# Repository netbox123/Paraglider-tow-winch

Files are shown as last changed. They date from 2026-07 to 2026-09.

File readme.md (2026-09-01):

# Paraglider Tow Winch

Version 0.2

An open-source electric tow winch for paragliding, designed with safety, reliability and maintainability as the primary goals.

The project combines:

- Parametric mechanical design in FreeCAD
- Python-generated CAD models
- Direct rope tension measurement using a load cell
- PID-controlled electric drive
- Automatic level winding using a self-reversing traverse screw
- Open documentation and engineering calculations

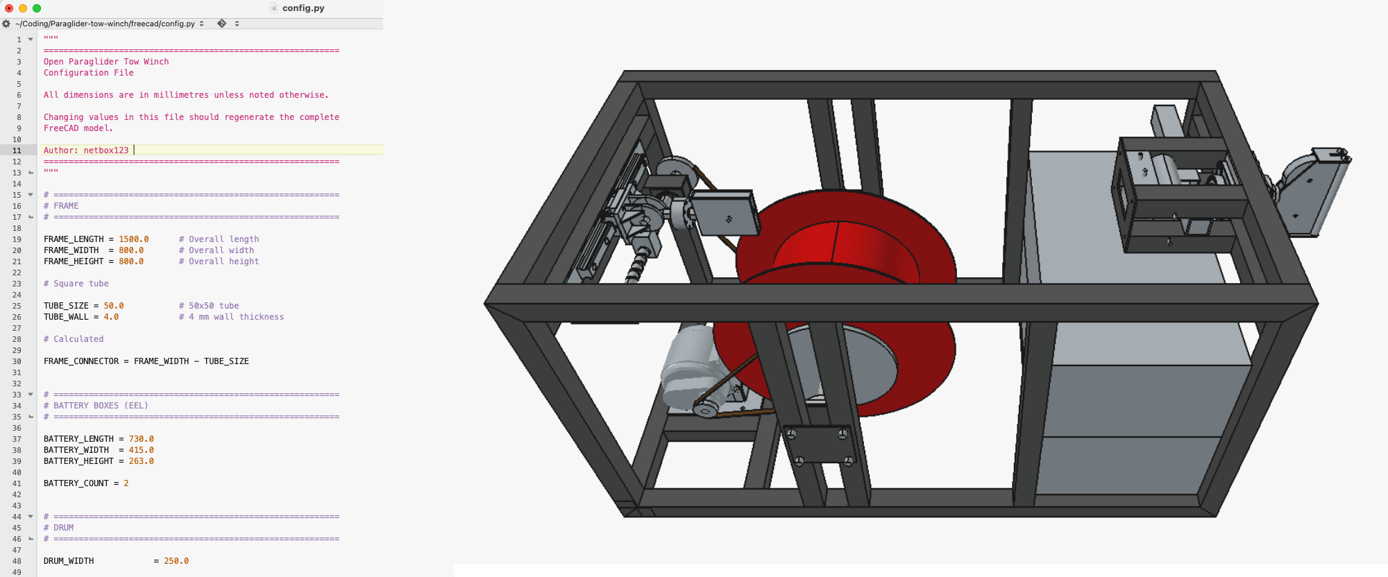
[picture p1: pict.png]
Parametric FreeCAD model of the tow winch frame, drum, drivetrain, level wind and battery boxes


## Project Goals

The aim is to build a tow winch that:

- Maintains constant tow force independent of drum diameter.
- Winds the rope neatly during both retrieval and payout.
- Minimizes side loads on the level wind mechanism.
- Is easy to maintain using commercially available components.
- Can be reproduced and improved by other clubs.

## Current Concept

### Frame

- 1500 × 800 × 800 mm
- 50 × 50 × 4 mm square steel tube

### Drum

- Width: 250 mm
- Core diameter: 390 mm
- Flange diameter: 590 mm
- 5 mm steel shell
- 5 mm steel flanges
- 50 mm shaft
- Internal stiffening discs

### Power

Planned motor:

- QS165 12 kW
- 2.37:1 gearbox

### Rope

- 3 mm Dyneema
- Approximately 1500 m
- Typical tow tension: 40–100 kg

### Level Wind

A mechanically synchronized self-reversing traverse screw ("diamond screw" or "level wind screw") is used instead of a stepper motor.

Advantages:

- Works automatically in both winding directions.
- Always remains synchronized with the drum.
- No electronic positioning required.

### Tension Control

Tow force will be measured directly with a load cell mounted beneath the moving guide pulley.

Benefits:

- Direct measurement of rope tension.
- Independent of drum diameter.
- Independent of gearbox efficiency.
- Independent of motor current.
- Improved PID control.

## Software

The FreeCAD model is generated from Python macros (`freecad/`), one module per subsystem, all driven from a single [`config.py`](freecad/config.py).

The intention is that the complete winch can be regenerated from a small set of configuration parameters.

Modules built so far:

- Frame (hollow mitred tube)
- Battery boxes
- Drum (barrel, flanges, shaft, bearings)
- Motor mount and chain drivetrain (motor, sprockets)
- Rope intake (self-aligning swivel, rollers, guide wheels, line cutter)
- Level wind (Hiwin linear rail, self-reversing screw, flange bearings)
- Winding pulley and load cell mount (rod-end pivot)
- Operator-display panel-mount frame ([`gigadisplay_holder/`](gigadisplay_holder/) - a separate small parametric part, 3D-printed, fitted to the real GIGA Display Shield)

Still open:

- Electronics firmware - mainboard PCB (ESP32-S3) is designed, placed, routed and ready to order (see [docs/electronics.md](docs/electronics.md)); firmware itself has only a first communications skeleton so far, no control logic yet (see [docs/software.md](docs/software.md))
- CAN vs. analog throttle control - Fardriver's CAN61 protocol spec is in hand but not yet confirmed on real hardware; analog throttle kept as the wired fallback either way
- Frame cross-member mitres
- Motor mount bracket (currently a placeholder)

### Running the model

1. Install [FreeCAD](https://www.freecad.org/) (1.1 or newer).
2. Open FreeCAD and use **Macro → Macros… → Execute** to run [`freecad/main.py`](freecad/main.py), or open it in the built-in Python console and run it directly.
3. [`main.py`](freecad/main.py) creates a new `TowWinch` document and builds the complete model from [`config.py`](freecad/config.py). Edit values in [`config.py`](freecad/config.py) and re-run the macro to regenerate the model.

The model can also be regenerated headless (no GUI) with `freecadcmd freecad/main.py`, useful for scripted checks.

The operator-display frame in [`gigadisplay_holder/`](gigadisplay_holder/) is a self-contained parametric part with its own `config.py`; build it with `freecadcmd gigadisplay_holder/build.py`. See its [README](gigadisplay_holder/README.md).

## Status

The FreeCAD model is parametric and covers the mechanical structure end-to-end: frame, drum, drivetrain, rope intake and level wind. The electronics mainboard (ESP32-S3) is fully designed - schematic and PCB placed/routed, ready to order (see [docs/electronics.md](docs/electronics.md)). Firmware work has started: the GIGA/pilot-handheld JSON protocol is defined and a first communications-only skeleton exists (see [docs/software.md](docs/software.md), [`firmware/esp32_mainboard/`](firmware/esp32_mainboard/)) - the real control system (PID, CAN61, sensors) is not built yet.

Fabrication of the frame has already started in parallel with the CAD work (see [docs/build_log.md](docs/build_log.md)).

See [docs/todo.md](docs/todo.md) for the detailed, up-to-date task list.

## Documentation

- [Mission statement](docs/mission_statement.md)
- [History and design philosophy](docs/history.md)
- [Control philosophy](docs/control_philosophy.md)
- [Electronics architecture](docs/electronics.md)
- [Software architecture](docs/software.md)
- [Design decisions](docs/design_decisions.md)
- [Rope / drive train calculations](docs/rope_calculations.md)
- [Build log](docs/build_log.md)
- [Todo list](docs/todo.md)

## Contributions

Suggestions, calculations and constructive criticism are welcome.

The goal is to produce a safe, well-documented tow winch that can be used and improved by the paragliding community.

---

*Work in progress.*

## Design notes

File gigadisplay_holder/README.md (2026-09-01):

# GIGA Display Shield — panel-mount frame

A 3D-printed frame that mounts the Arduino GIGA Display Shield into the
front panel of the winchman's industrial electro box. It replaces the
shield's original snap-together case: here the industrial box *is* the
enclosure, so this part only has to provide the bezel, the panel
transition and the shield's four mounting standoffs.

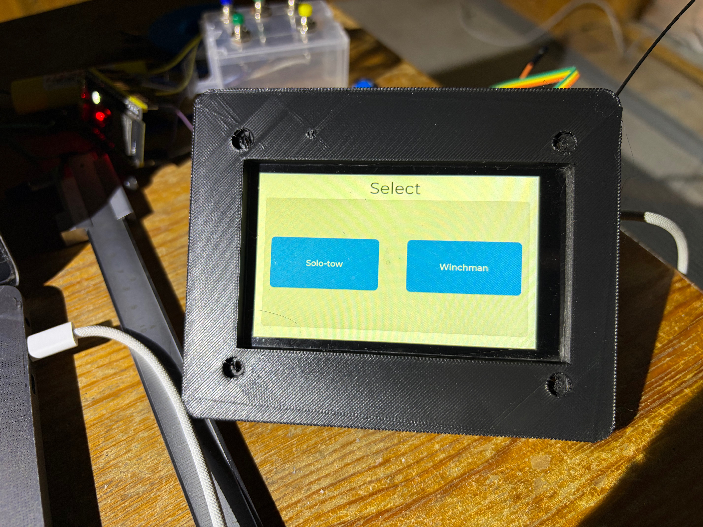
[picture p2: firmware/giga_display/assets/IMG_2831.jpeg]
Fit test, 2026-09-01 — real GIGA Display Shield mounted in the printed frame, running the operator UI's mode-select screen


## Design

- **Front flange** — the visible lip. Sits on the *outside* of the panel
  and hides the jigsaw-cut edge. Glued in, no flange screws.
- **Collar** — steps back from the flange and plugs through the cut hole.
  Its outer envelope is the size the jigsaw hole must be cut to
  (**112 × 86 mm**, with a small corner relief radius so the cut can turn
  each corner).
- **Four standoff bosses** inside the collar, on the shield's own
  `96 × 70 mm` M3 bolt pattern. The shield screws to these from behind;
  each boss tip sits `LCD_TO_PCB_HEIGHT` (6.45 mm) below the front face so
  the LCD glass ends up flush with the bezel.
- **LCD window** — the full glass module (98 × 58 mm) shows through.
- **RGB LED (DL1) light-pipe hole** — a straight 1.9 mm through-hole, to be
  filled with a short length of clear acrylic rod.
- **Screw-head counterbores** on the front face (6.2 × 2.8 mm) for M3
  bolts with a 5.5 mm head, seated just below flush.

Outer envelope: **128 × 102 × 7.5 mm**.

The reference geometry (bolt pattern, LCD window, glass-to-PCB depth) was
first derived from a boundary analysis of
`../freecad/drawings/Giga display shield case top.stl`. The first test
print was dimensionally sound but the window size and position were off;
every dimension was re-measured from the real board on 2026-09-01 and the
second print fits (photo above).

## Building it

Everything is driven from [`config.py`](config.py). Regenerate the model
and export the STL with:

```
/Applications/FreeCAD.app/Contents/Resources/bin/freecadcmd build.py
```

(or run `build.py` from FreeCAD's Python console). It writes
`GigaDisplayHolder.FCStd` and `giga_display_frame.stl`, and prints the
bounding box / solid-validity check.

The entry script is `build.py`, **not** `main.py` — FreeCAD's macro-path
lookup intercepts the basename `main.py` and would run the winch model's
`freecad/main.py` instead.

## Still open

- **`PANEL_THICKNESS`** is a 3.0 mm placeholder. Set it to the real front-
  panel thickness of the box once that's picked, then reprint. `COLLAR_HEIGHT`
  follows it automatically.
- The LED light-pipe hole position assumes the "3 mm from top / 26.5 mm
  from left" measurement was to the hole *centre*. Confirm it lines up
  once the shield is bolted in.

## Slicing

Printed on a FlashForge, ~6 h. Support goes under the standoff-boss
overhangs (they project from the flange's back face into the collar
cavity); that placement has printed cleanly twice. The front face has the
usual FDM top-surface texture and wants a light sand.

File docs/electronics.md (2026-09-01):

# Open Paraglider Tow Winch

# Electronics Architecture

Version 0.2

---

## Overview

The electronics are split into three nodes, kept deliberately separate so that display/communication work can never introduce jitter into the safety-critical force control loop (see [control_philosophy.md](control_philosophy.md)):

```
Load Cell ──▶ ESP32 (PID loop) ──CAN──▶ Fardriver Controller ──▶ QS165 Motor
                  │  ▲
              UART│  │UART
                  ▼  │
         Arduino GIGA R1 + Display        LoRa ◀────────────▶ LoRa
              (operator UI)          (winch-side module)   (pilot handheld)
```

This is a design decision, not yet built - no firmware or wiring exists for this architecture yet.

---

## Motor Controller: Fardriver ND961200-CAN

The CAN variant was chosen over the standard serial-only version for noise immunity next to a high-current controller and for clean telemetry output.

**RESOLVED 2026-08-03: throttle/torque command by CAN is real and documented.** The commonly available reverse-engineered manual only documents CAN as telemetry-out / BMS-style status-in (SOC, discharge current limit, gear, brake, charge-enable) - no message there for commanding throttle, torque or current. A fuller official-style parameter manual then surfaced a real **"driverless"/VCU protocol** (named control-ID variants "driverless 9" / "driverless 59", OEM VCU protocol options in section 9.18) confirming the capability exists, but without publishing the actual frame layout - that's gated behind picking a named protocol variant. Fardriver support (info@far-driver.com) provided the real protocol document on request: a **20ms-cycle VCU control frame** (extended ID `0x10F80807`-`0x10F8F807` / standard ID `0x101`-`0x1F1`) carrying gear, brake, control-mode select (throttle/torque/speed), and a signed 16-bit setpoint - with a **150ms CAN-loss timeout** that falls back to the analog line-throttle input. The controller also broadcasts a matching 20ms telemetry frame (`0x10F90708`-`0x10F908F8`) with realized torque/current/speed, feeding directly into the ESP32's tension-PID loop.

**Firmware plan updated accordingly:** command the motor directly via CAN (torque mode is the likely pick for tension control) rather than building an analog-throttle-spoof circuit - pending confirming the ordered ND961200-CAN unit actually implements this protocol on real hardware (not yet tested). Must also **enable CAN control in the Fardriver PC config app** - a config toggle (the doc's "control type=48"), not automatically active just because the hardware variant supports it.

**Analog throttle kept as a documented fallback only, not the primary build target** - the 150ms CAN-loss timeout relies on the controller's analog throttle input holding a valid, never-floating voltage at all times (see the gotcha below), so the physical wiring for it still needs to exist even though the ESP32 won't drive it in normal operation.

**Throttle voltage reference (for the analog fallback):**

- E-bike handlebar throttle: 0.8-0.9 V idle, 4.1-4.3 V full
- 12 V accelerator pedal: 0-0.2 V idle, 4.6-4.8 V full

**Gotcha - throttle plug protection:** unplugging or floating the throttle signal triggers a fault bailout on the controller. The emulated throttle circuit must always present a valid voltage and must never float, in every firmware state including startup and fault handling - this now matters specifically as the CAN-loss fallback path, not the everyday control path.

---

## Battery: 2x EEL 48V boxes, one 30-cell string under a single BMS

Two EEL 48V battery box enclosures house the cells (physical envelope already modelled in [`battery_box.py`](../freecad/battery_box.py) / [`config.py`](../freecad/config.py), `BATTERY_COUNT = 2`) - but electrically this is **one continuous 30-cell series string managed by a single BMS**, not two independently-managed 48V boxes stacked in series as originally planned.

**Why not two independent BMS units in series (the original plan):** each EEL box ships with its own Seplos Smart BMS 3.0. Its own spec PDF states plainly it **cannot be used in series** - each unit's analog sensing/balancing/comms is referenced to its own pack's negative terminal, so stacking two independently-referenced 48V boxes would float the top box's entire BMS 48-57V above true system ground, which consumer BMS analog front-ends generally aren't designed to tolerate (risk of damaged electronics or corrupted balancing/comms).

**Decision: replace both boxes' Seplos BMS units with a single BMS spanning all cells as one series string** - **ANT Smart BMS, 30S variant** (420A continuous / 1050A peak for 10s, 112V-rated, LiFePO4). Chosen over two other 30-32S-class candidates considered (QUCC QJ-2532U4CB, Heltec Energy 2-32S relay-based) mainly because of our own 3-year trouble-free history running an ANT BMS on an unrelated system, and because the Heltec relay-based unit's spec sheet never publishes a DC breaking/interrupting current rating for its main disconnect - the number that actually matters for a relay switching large DC currents without welding its own contacts shut. The 1050A/10s peak rating comfortably covers the CAN61 protocol's own torque-ramp rate limit (max 1/32 of full torque per 20ms tick - even a full 0-to-max ramp takes >=640ms).

**Cell count dropped 16 -> 15 per box (30 total, not 32):** the Fardriver ND961200's 115V overvoltage disconnect threshold left only ~1V margin at the original 32 cells x 3.65V max = 116.8V. Dropping to 30 cells total (15/box) gives 30 x 3.65V = 109.5V max - ~5.5V (4.8%) margin, covering BMS balance overshoot, charger overshoot, and regen-braking voltage spikes.

**Battery wiring quality matters more than usual here:** during regen/braking, current reverses, so IR drop in the wiring *adds to* (not subtracts from) the voltage the controller sees - thin/loose wiring directly erodes the overvoltage margin the cell-count change was meant to buy back. Plan for heavy-gauge wiring and clean, torqued lugs as a second, independent lever alongside the cell-count reduction.

**Open item:** the tows-per-charge estimate below still uses the original 32 kWh two-independent-16S-box figure - not yet recalculated against the 30-cell/single-string architecture (slightly fewer cells at a slightly higher string voltage; expected to land in the same ballpark, but not confirmed against the cells' real Ah rating).

### Tows per charge (simple estimate, capacity figure not yet updated for the 30-cell architecture above)

Energy used per tow = tow force x length of rope reeled in (work = force x distance), reduced by drivetrain losses (chain, bearings, gearbox friction) before it reaches the rope.

Assumptions (first-order, adjust once real tow profiles are measured):

- Average tow force: 70 kgf (between `TOW_FORCE_MIN` 40 kg and `TOW_FORCE_MAX` 100 kg)
- Rope paid out per tow: full `ROPE_LENGTH`, 1500 m (worst case - a shorter release height uses proportionally less energy)
- Mechanical loss: 30%

```
Mechanical work at the rope   = 70 kgf x 9.81 x 1500 m = 1.03 MJ = 0.286 kWh
Electrical energy from battery = 0.286 kWh / (1 - 0.30)          = 0.409 kWh per tow

Tows per full charge = 32 kWh / 0.409 kWh ≈ 78 tows
```

Simplified: constant tow force, full rope payout, no regen credited, no auxiliary/electronics draw. A shorter typical release height or effective regen on payout would push this number up; a higher average force would pull it down. Large enough either way that tows-per-charge becomes known through use, so live SOC monitoring in the control loop still isn't needed - SOC can be read off the BMS's own display/app.

---

## ESP32 Control Node

Runs the PID tension-control loop (load cell feedback -> throttle/torque command) and speaks CAN to the Fardriver controller.

**Why ESP32:** chosen over a Raspberry Pi because Linux scheduling jitter is a poor fit for a real-time actuation loop, and over a Teensy/STM32 because the winch's mechanical time constants (rope/motor, tens to hundreds of ms) don't need Teensy-level determinism. Teensy 4.x remains the upgrade path if the ESP32 ever feels tight.

**Variant: ESP32-S3, final form factor an N16R8 DevKitC-1 plug-in board** - superseded the earlier classic-ESP32 (WROOM-32) pick once mainboard PCB work started (see "Mainboard PCB" below for the full core-selection history, including a brief bare-WROOM-1-module stage before settling on the DevKitC-1). The S3's native USB (no external UART bridge needed for programming/debug) and extra GPIO/ADC headroom outweighed the classic ESP32's slightly larger e-bike/CAN-reverse-engineering example-code precedent, which was the original reason for that pick.

**CAN bus count:** originally assumed two buses were needed (Fardriver + battery BMS), which drove a comparison between dual-CAN dev boards (LilyGO T-2CAN) and single-CAN boards with extra I/O (Waveshare ESP32-S3-POE-ETH-8DI-8DO). **Resolved:** the battery CAN link was dropped - the pack is 32 kWh, large enough that pulls-per-charge become known through use, and SOC can simply be read off the battery box's own display. A single CAN bus (Fardriver only) is sufficient, so a plain ESP32 with native TWAI (only needs an external transceiver such as an SN65HVD230) is viable. The Waveshare board's isolated digital I/O (8 in / 8 out, optocoupled) remains attractive for winch safety I/O (e-stop, rope-end limit switch, contactor/relay control) and is still under consideration on that basis, independent of the CAN question.

**Analog throttle fallback (if CAN throttle command doesn't pan out):** a proper DAC output, e.g. MCP4725 over I2C, rather than the ESP32's built-in 8-bit DAC, for a cleaner and higher-resolution signal, calibrated to the controller's idle/full throttle voltage thresholds above.

---

## Pilot Handheld Remote

**Board:** [Heltec ESP32-S3 + SX1262 LoRa V4 touchscreen](https://www.amazon.com/Heltec-Development-Touch-2800mAh-Meshtastic/dp/B0G58QZYH9) - 3.5" capacitive touch, GPS, 2800 mAh battery, aluminium case.

**Why not stock Meshtastic:** Meshtastic's mesh-routing stack adds unpredictable latency, unsuitable for a safety-critical e-stop link. The plan is custom **point-to-point LoRa firmware** (e.g. via RadioLib on the same SX1262 chip) instead of the full Meshtastic stack - the LoRa radio layer and the Meshtastic mesh protocol are independent, so this board's hardware doesn't require running Meshtastic.

**Why touchscreen alone isn't enough:** a touchscreen is a poor fit for an e-stop a pilot needs to hit instantly with gloves on. The touchscreen is kept for **status display only** (tension, SOC, etc.); actual control input goes through **physical tactile switches added to the case**. This board was specifically chosen because its aluminium enclosure is strong enough to drill and mount extra switches into, unlike a plastic dev-board case.

**Frequency band: EU868**, not EU433. EU433 has a theoretically lower-frequency propagation edge but needs a physically longer antenna (~17 cm quarter-wave vs. ~8.6 cm for EU868) - not wanted on a handheld. EU868 also allows up to 500 mW EIRP on its special sub-band (vs. ~10 mW typical for EU433) and is the more mature, better-supported band for this hardware.

**Must match on both ends:** the winch-side LoRa module (to be added to whichever ESP32 board is chosen) must be ordered/configured for the same EU868 band, or the two ends will not talk to each other at all. Double-check the exact SKU when ordering - don't assume a generic "LoRa module" listing defaults to the right region.

**Barometric height, not GPS, for the tree-height trigger.** GPS vertical accuracy (typically ±10-20 m, worse on a cold fix right at launch) is too coarse for a threshold in the 10-30 m band (±4 m accuracy is the actual target and is sufficient). A cheap I2C MEMS barometric sensor (BMP388/BMP390/DPS310 class) easily matches that on raw resolution (the same sensor family used in dedicated variometers, e.g. our own Brauniger, which resolves ~30 cm). **Auto-zeroed at the start of each tow** (same convention as a vario's ground-level reset), so the reading is height-above-launch, not absolute altitude - weather-driven barometric drift is a non-issue over the seconds it takes to climb through tree height.

**Flagged - don't underestimate the filtering.** Raw sensor resolution is not the hard part; the reason dedicated varios like Brauniger/Flytec are trusted is the filtering on top of the raw pressure reading: temperature compensation (MEMS dies drift with temperature), rejecting dynamic-pressure noise from motion/wind/airflow over the vent without adding response lag, and balancing fast reaction against noise rejection - this is genuine, non-trivial DSP work, not a moving average. Two more realistic paths than writing a filter from scratch:
- Reuse a proven open-source vario filter implementation rather than inventing one - still searching for these.
- Check whether the Brauniger (or another owned instrument) already exposes a serial/Bluetooth telemetry output (many flight instruments do, e.g. NMEA-style vario sentences) - reading a unit already known to be trustworthy sidesteps reimplementing sensor fusion entirely.

**Sensor + library candidate, found 2026-08-01:** BMP388 via the Adafruit BMP3XX library ([tutorial](https://randomnerdtutorials.com/arduino-bmp388/)), I2C (SDA/SCL) or SPI. Covers part of the filtering concern above in hardware: the sensor itself does oversampling (2x-32x) and has a configurable IIR filter (coefficient up to 127), plus its own temperature-compensation calibration - so temp drift and basic noise smoothing don't need to be written from scratch, only tuned (oversampling/IIR settings, output data rate up to 200 Hz). Still doesn't cover wind/dynamic-pressure noise rejection specifically - that needs bench-testing outdoors before trusting it as the auto-trigger. Sea-level-pressure calibration (`SEALEVELPRESSURE_HPA` in the tutorial) is irrelevant here since the design auto-zeros per tow - only the pressure delta from the zero point matters, not absolute altitude.

**Second candidate, same day: BMP280.** [Datasheet](https://cdn-shop.adafruit.com/datasheets/BST-BMP280-DS001-11.pdf) specifies **±0.12 hPa relative accuracy, equivalent to ±1 m altitude** (950-1050 hPa @ 25°C) - comfortably inside the ±4 m target - plus 1.3 Pa RMS noise and only 12.6 cm/K temperature-offset drift. Older/cheaper/lower-power predecessor to the BMP388, same Bosch APSM MEMS lineage, same IIR-filter/oversampling hardware features. Has a working reference implementation: [arduino_variometer](https://github.com/01ive/arduino_variometer) (MIT license, ~€26 BOM: Arduino Nano + BMP280 + MPU6050 accel + piezo buzzer) - a real built vario using this exact chip, worth reading for wiring/part choices even though its filtering approach isn't documented in the repo itself (would need to read the source directly). Still undecided between BMP280 and BMP388/BMP390/DPS310 - more research pending before committing.

GPS is kept on the handheld for **track logging only** (nice-to-have, not part of the safety trigger).

---

## Operator UI: Arduino GIGA R1 WiFi + GIGA Display Shield

Display and operator input only - deliberately kept **out of the actuation loop** so display/WiFi work never introduces jitter into the control timing.

The GIGA R1's dual-core STM32H747 lets the M4 core handle display rendering while the M7 core runs the app logic. The GIGA and the ESP32 talk over a simple UART link: the ESP32 streams tension/RPM/current/fault state to the GIGA for display, and the GIGA sends operator command input back.

**Gotcha:** the GIGA Display Shield looks Mega-shield-footprint compatible but needs a middle high-density connector that only exists on the GIGA R1, and the GIGA runs 3.3 V logic vs. the Mega's 5 V - it cannot be stacked on a plain Mega board.

**Physical mounting:** the shield drops the plastic snap-case and mounts straight into the front panel of the winchman's industrial electro box via a 3D-printed bezel/frame - flange on the outside, collar through a jigsaw-cut hole, four printed standoffs the shield screws to from behind, and a light-pipe hole for the RGB LED. Parametric FreeCAD part in [`gigadisplay_holder/`](../gigadisplay_holder/) (fitted to the real board 2026-09-01); the box's panel thickness is still a placeholder pending the box choice.

---

## Unified Operator Command Protocol

The GIGA (winch operator) and the pilot's LoRa handheld both act as command sources for the ESP32, carrying the **same command/telemetry protocol over two different transports** - UART for the GIGA, LoRa for the handheld. The ESP32 parses one protocol regardless of which link a frame arrived on, rather than maintaining two separate command sets.

- **Winch operator (GIGA):** full command surface - tension setpoint/profile selection, state machine control, fault reset, full telemetry display (tension, RPM, current, fault state).
- **Pilot handheld:** deliberately minimal input, matched to what a pilot can operate instantly with gloves on - a **deadman button** and an **"above tree height" button** (manually commits the ramp to the pilot-weight tow force profile), both as physical tactile switches, not touchscreen controls. The touchscreen stays status-display-only (tension, SOC, etc.); barometric height (see above) is intended to eventually derive the tree-height transition automatically rather than relying solely on the manual button.

---

## Mainboard PCB (KiCad)

Schematic + PCB for the ESP32-S3 control node, in `kicad/winch_mainboard/` (KiCad 10). **Design is complete and ready to order**: ERC-clean (0 violations) and DRC-clean (0 real violations, 1 cosmetic silkscreen-text overlap on U1), fully placed and routed, board outline 180.5x114mm.

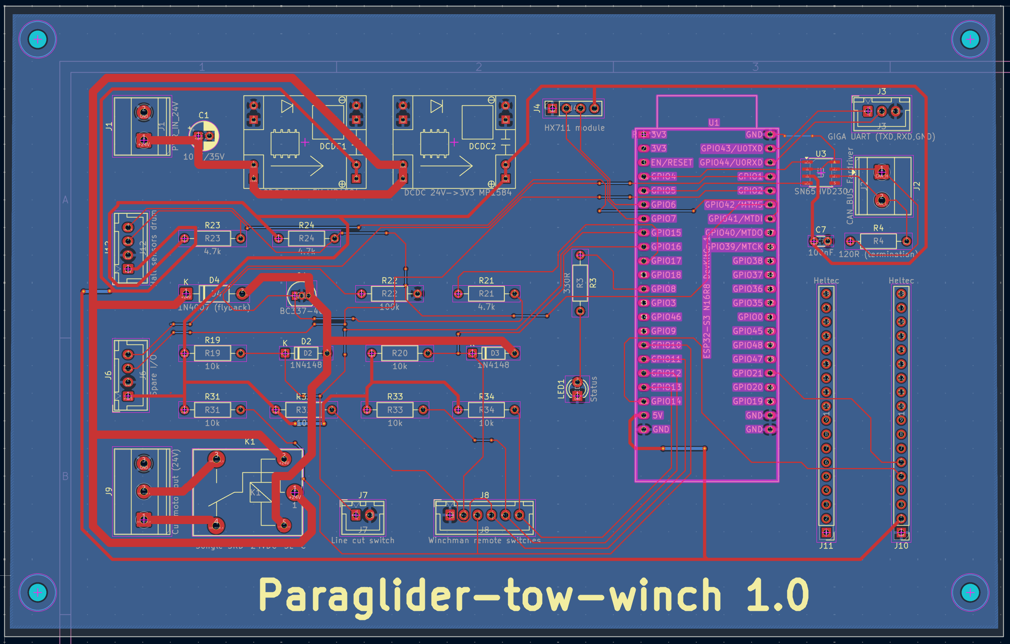
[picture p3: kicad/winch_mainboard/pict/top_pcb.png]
Top copper routing

*Top copper layer, fully routed - red traces on F.Cu, GND pour on the back layer.*

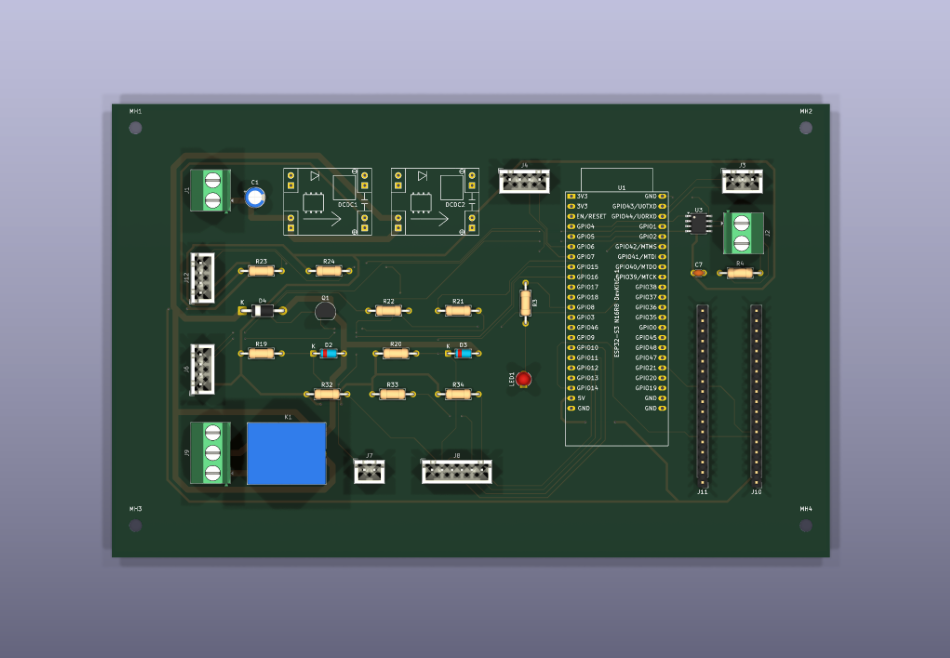
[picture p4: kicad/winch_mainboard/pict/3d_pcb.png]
3D render

*3D render of the finished board.*

**Core: ESP32-S3 N16R8 DevKitC-1 (plug-in board, 2026-08-15 - changed from a bare WROOM-1 module).** Briefly used a bare WROOM-1 module (symbol/footprint from [JustasBart/ESP32-KiCad-libraries](https://github.com/JustasBart/ESP32-KiCad-libraries), verified pin-for-pin identical to the official Espressif PCM library it replaced), but then switched to a plug-in DevKitC-1 board instead - reasoned to be much easier to route (a 2-row 2.54mm header is a far more forgiving target for hand/auto-routing than a dense 3-edge castellated SMD module). Symbol/footprint also sourced from JustasBart's repo (same library, different part - `ESP32-S3-DevKitC`, 44-pin 2-row THT header, confirmed against a real product listing for this exact board). The devkit is self-sufficient (its own onboard USB-C, RST/BOOT buttons, and 3.3V regulator), so several support components this board used to provide became redundant and were **removed**: the USB-C connector (J5) and its CC resistors/VBUS diode (R5/R6/D1), the EN pull-up/reset button (R1/SW1/C6), the GPIO0/BOOT pull-up/button (R2/SW2), and the module decoupling caps (C4/C5). Only **+5V** (feeds the devkit's onboard regulator) and **GND** are wired for power - the devkit's own 3V3 output pins are deliberately left unconnected (never tie two independent regulator outputs together), as are EN/BOOT/USB D+/D- (the devkit drives these internally). Net map is by **GPIO identity**, not pin position - the devkit's header pin numbers don't correspond to the old module's pin numbers at all, only the GPIO each carries does.

**Power:** a Victron 96V-to-24V DC/DC converter (external, off-board) feeds the mainboard at +24V. Two independent plug-in buck-module headers generate +5V and +3V3 directly from +24V (no linear regulator - a 24V-to-3.3V LDO would dissipate too much heat for continuous tow duty). Both use the real **MP1584 buck module footprint** (community footprint from [kubabuda/misc_footprints](https://github.com/kubabuda/misc_footprints), bundled locally in `kicad/libraries/misc_footprints/` - the repo's footprint predates KiCad's modern format, converted in place with `kicad-cli fp upgrade`). **Pad-to-function mapping is a reasonable best guess, not confirmed:** the footprint has no per-pin silkscreen labels, just 4 pads (2 on the input side, 2 on the output side) - pin1/2 = input, pin3/4 = output is the standard physical layout for this module family, but which exact pad is +/- within each side isn't confirmed from a labelled pinout. **Verify against the real module's own silkscreen (VIN+/VIN-/VOUT+/VOUT-) before soldering.** +5V feeds the ESP32-S3 devkit's onboard regulator (see Core, above); the board can also be bench-programmed through the devkit's own USB-C port without the 24V supply connected, same as before, just via the devkit's own port now rather than a dedicated connector on this board.

**Load cell amp (HX711):** header only, not the HX711 chip itself - a standard off-the-shelf dual-channel HX711 breakout module mounts **flat, directly on the mainboard** (not via a cable): J4 is a `PinSocket_1x04_P2.54mm_Vertical` socket, and the module's own 4-pin header (JP2) plugs straight down into it, shield-style. Its 6-pin load-cell terminal row (E+/E-/A+/A-/B-/B+, only one channel used) faces away from the mainboard. **Pin order is reversed from the module's own printed silkscreen** (`GND, DT, SCK, +3V3` on J4 pins 1-4, not `VCC, SCK, DT, GND`) - this is deliberate, not a mistake: with the module mounted header-pins-up/load-cell-side-down (the intended orientation), the header reads in the opposite direction from the module's own top-down silkscreen labels. Confirmed by physical test-fit, not just the (mirrored) product photo. **Powered from 3.3V, not 5V** - deliberate: the HX711's DT output would swing to whatever voltage powers it, and a 5V-powered HX711 driving DT into the ESP32-S3's 3.3V-only (not 5V-tolerant) GPIO would risk damaging it. Running the HX711 at 3.3V instead is common practice and avoids needing a level shifter, at the cost of slightly reduced load-cell excitation range (not expected to matter here).

**CAN:** SN65HVD230 transceiver (3.3V, matches the ESP32-S3 GPIOs directly, no level shifting needed) plus a 120R termination resistor at the connector. If the Fardriver end of the bus already terminates itself, this resistor may need removing - not yet confirmed.

**USB-C:** native USB (ESP32-S3's D+/D- direct to the connector, no external UART bridge) for programming and a debug/console link, independent of the CAN/UART links.

**GIGA UART (winchman display):** dedicated 3-pin locking connector (ESP32_TXD, ESP32_RXD, GND) on UART0, separate from the native-USB pins - the two links don't share hardware.

**Line-cut system - the safety-critical addition.** Two physical switches (one mounted on the winch, one on the winchman remote) can each fire the line-cutter relay **directly in hardware**, independent of firmware:
- Each switch is a simple GPIO-monitored input (10k pull-up to 3V3, active-low), so firmware can read/log which switch (if either) was pressed.
- Each switch's sense line *also* feeds a diode (1N4148, cathode toward the switch) into the shared `RELAY_COIL_LOW` node - closing either switch pulls that node toward GND through its own diode, energising the relay coil **regardless of whether the ESP32 firmware is running.**
- Firmware has its own independent path to the same node: a GPIO through a base resistor drives an NPN transistor (BC337-40) that can also pull `RELAY_COIL_LOW` low - this is the "should be possible to initiate by software too" path. A base pulldown resistor keeps the transistor off by default (e.g. during boot, before firmware sets the pin).
- The relay (SPDT, 24V coil, e.g. Songle SRD-24VDC-SL-C) switches +24V through to a screw-terminal output for the cutting motor. A flyback diode (1N4007) sits directly across the coil.
- **Relay part chosen and footprint fully wired (2026-08-15): Songle SRD-24VDC-SL-C.** Its datasheet (via the KiCad footprint's own citation - the physically-identical Sanyou SRD-series part family) confirms COM is the isolated pad and the coil pins are the close pair, but does not print which of the remaining two pads is NO vs NC (common gap in budget relay datasheets, and this session couldn't resolve it any other way either - see memory for the full trail). **Rather than guess on a circuit that switches the cutting motor, both relay contacts are wired out separately** (`CUT_MOTOR_A`/`CUT_MOTOR_B`) to a 3-position terminal (J9) alongside GND, instead of committing one contact to a fixed `CUT_MOTOR_OUT` net - wire the actual motor between GND and whichever terminal tests as NO (continuity to COM while the relay is unpowered = NC, the other is NO) once the part is in hand. The unused terminal is spare, or usable later as an NC "not cutting" sense input. J9's silkscreen spells out the pinout directly (`1/2=K1 contacts A/B (verify NO), 3=GND`) so this doesn't need to be re-derived from the schematic when wiring up the real board.
- **Inherent limitation, not fixable in the circuit:** if the +24V supply itself is lost, no cut path works (mechanical/spring-loaded fallback would be the only way around this, and isn't part of the current design).

**Winchman remote (J8) - 6 switches on one 7-pin locking connector** (shared GND + one sense line each): line cut, emergency stop, tension +5kg, tension -5kg, tension reset-to-programmed, release. Only the line-cut switch gets the hardware relay bypass described above - the other five (e-stop, both tension nudges, tension reset, release) are plain firmware-read inputs (10k pull-up each), since they're software state-machine actions rather than a physical safety action to bypass into - e-stop "brings the state to idle," which is inherently a firmware concept, not a hardware one.

**A 7th pin added to the winchman remote connector (now J8, 7-pin JST-XH) for a "release" switch** (ends a tow cleanly without depending on the GIGA link - `state_cmd:"release"` is otherwise GIGA-only, see [software.md](software.md#field-authority)). Carries `GPIO2` (previously only reachable via J6's spare `SPARE_GPIO2` pin - both still resolve to the same net; J6 pin 3 is now a redundant second access point, harmless to leave as-is). Has its own dedicated 10k pull-up (**R35**, `+3V3` to `SPARE_GPIO2`), matching the other four winchman-remote switches - not an internal-pull-up-only bodge. Schematic/PCB done (new `Conn_01x07` symbol, J8 footprint swapped to `JST_XH_B7B-XH-A_1x07`, R35 placed at a DRC-clean location) and ERC/DRC clean; the copper routing for the 3 new connections (J8 pin 7, R35's two pads) is left for manual routing, same convention as the rest of this board.

**Pre-order check caught a real omission (2026-08-16):** the e-stop pull-up resistor (R31, 10k, `+3V3` to `ESTOP_SENSE`) existed in the schematic but had no footprint anywhere on the PCB - its three siblings (the tension +/-/reset pull-ups) were all present, only this one had been dropped somewhere along the way. Fixed: added and routed. Worth remembering as a general check before ordering any board - a schematic/PCB reference cross-check (every schematic component should have a matching PCB footprint, and vice versa) catches this class of silent omission that ERC/DRC alone won't, since a component that was never placed doesn't show up as an "unconnected pad."

**LoRa (winch-side, talks to the pilot's Heltec SX1262 handheld) - architecture changed from the original plan.** We chose a **Heltec WiFi LoRa 32 V4** board for this. That board has its *own* ESP32-S3 driving its onboard SX1262 (plus an OLED, GNSS header, USB-C, and battery/solar inputs) - it's a full standalone dev board, not a bare radio breakout to drive directly over SPI as originally planned. Its exposed "LoRa_NSS/SCK/MOSI/MISO/RST/BUSY/DIO1" pins (from the board's own pin map) are already committed internally to its onboard radio - not available to reach in from outside.

Treated the same way the GIGA display already is: a **UART-attached peripheral** running its own firmware, not something this mainboard drives directly. **Connector footprint resolved (2026-08-15):** the Heltec board's own reference KiCad files and official pin-map confirm the real physical connector is **two 1x18, 2.54mm-pitch THT headers** (Heltec's own "J2" and "J3" designators) rather than a single small cable connector. Only J2 is wired - pins 1 (GND), 2 (5V), 5 (U0RXD, cross-connects to our `LORA_TXD`), 6 (U0TXD, cross-connects to our `LORA_RXD`) - the other 14 pins on J2 and all 18 on J3 (a second full header exposing more of the Heltec's GPIOs) are left completely unconnected/reserved for future use, same pattern as the spare I/O header. "5V"/"Ve" (J2 pins 2-4) is the documented external-supply input pin (confirmed from the real pin-map image, not just assumed from typical dev-board convention as before) - the Heltec's "3V3" pins are its regulator *output*, not an input, so still not used to power it.

This swap also freed 5 GPIOs (was 7 pins for direct SPI control, now 2 for UART) - a big improvement to the GPIO budget below.

**Drum-direction hall sensors:** one locking connector for both sensors (they sit close together near the drum flange and share a cable run) - shared +5V/GND, two separate sense lines. Powered at 5V for wider sensor-part compatibility, but each sense line is pulled up to 3V3 (not 5V) rather than whatever the sensor's own supply is - assumes an open-collector sensor output (common for digital Hall switches), so the GPIO never sees more than 3.3V regardless of the sensor's own supply voltage. Same reasoning pattern as the HX711 3V3 choice above.

**State-machine indicator LEDs and I2C multiplexer - REMOVED (2026-08-15).** The original design had a vertical row of 6 state LEDs (idle, calibrating, start procedure, low-power tow, normal tow, releasing) driven through a PCF8574 I2C GPIO expander. Removed for simplification, along with its resistors (R25-R30, and the SDA/SCL pull-ups R35/R36) - the board's only remaining LED is the single direct-GPIO status LED (LED1). Frees GPIO9 and GPIO18 (was SCL/SDA) back to the spare pool.

**Real bug caught before it mattered (historical note):** the very first version of every LED on this board (the status LED and, briefly, the now-removed state-LED row) had **anode and cathode swapped** - the LED's cathode went to the series resistor/drive signal and its anode went straight to GND, which means it would never light under any drive condition (current can't flow anode-to-cathode with the anode pinned at 0V - reversed from the intended "GPIO sources current" or "expander sinks current" pattern). KiCad's ERC does not catch this - electrically the circuit is completely valid, just backwards - so it only surfaced from actually reasoning through current direction and confirming it against a rendered close-up of the symbol. Worth remembering for any future diode/LED addition: getting a clean ERC does not mean the polarity is functionally correct.

**Connector style:** locking connectors (JST-XH) for every off-board cable run - line-cut/winchman-remote switches, hall sensors, GIGA UART, HX711 - so nothing vibrates loose on a moving winch. Power/CAN/motor-output connections use Phoenix Contact MKDS 1,5 (5.08mm pitch) terminal blocks (our chosen part family; the 2-position member of the series, since all of this board's terminal blocks are 2-pin) - already inherently captive, and better suited to higher current than JST-XH. The buck-converter modules use their own real footprint (not a connector) since they're soldered directly to the board. The Heltec LoRa board is the one exception - it uses its own real 1x18+1x18 2.54mm pin-header footprint (J10/J11, see LoRa section above) rather than a JST cable connector, since that's the board's actual physical connector.

**Spare I/O header:** 9 unused GPIOs (1, 2, 9, 18, 38, 39, 40, 47, 48) plus 3V3/GND - GPIO9/GPIO18 joined the spare pool when the I2C state-LED expander was removed. J6 (the physical spare-I/O connector, 4 pins: `+3V3`, `GND`, `SPARE_GPIO2`=GPIO2, `SPARE_GPIO1`=GPIO1) currently only breaks out 2 of these; the rest are free on U1 but not yet wired to a header pin - worth revisiting when placement is redone. **`GPIO2`/`SPARE_GPIO2` is now the winchman remote's "release" switch line** (see above, now on J8 pin 7 with its own pull-up) - J6 pin 3 still carries the same net as a redundant spare tap. `GPIO1` (J6 pin 4) is still free.

**Pin map (ESP32-S3-DevKitC-1, N16R8 - GPIO identity carried over unchanged from the earlier bare-WROOM-1 design):**

| Function | Pin (GPIO) |
|---|---|
| CAN TX / RX | GPIO4 / GPIO5 |
| HX711 SCK / DT | GPIO6 / GPIO7 |
| Status LED | GPIO8 |
| Line-cut switch sense (winch / winchman remote) | GPIO15 / GPIO16 |
| Line-cut relay drive (software path) | GPIO17 |
| Winchman remote: e-stop / tension+5kg / tension-5kg / tension reset | GPIO10 / GPIO11 / GPIO12 / GPIO13 |
| Winchman remote: release (J8 pin 7, own pull-up R35) | GPIO2 |
| LoRa UART (Heltec board) TXD / RXD | GPIO14 / GPIO21 |
| Drum hall sensors A / B | GPIO41 / GPIO42 |
| GIGA UART TX / RX | GPIO43 (U0TXD) / GPIO44 (U0RXD) |
| USB D- / D+ | GPIO19 / GPIO20 (native USB, fixed pins) |
| Spare I/O | GPIO1, GPIO9, GPIO18, GPIO38, GPIO39, GPIO40, GPIO47, GPIO48 (GPIO2 earmarked for release, above) |

GPIO3, GPIO45, GPIO46 (strapping pins) and GPIO35-37 (used internally on the DevKitC-1's octal PSRAM, confirmed - this is the N16R8 variant, 16MB flash + 8MB octal PSRAM) are deliberately left unused, to avoid boot-strapping or PSRAM conflicts.

**Open items:**
- Buck module (MP1584) pad-to-function mapping is a geometry-based best guess, not confirmed from a labelled pinout - verify before soldering (see above).
- CAN termination resistor may need removing depending on the Fardriver end's own termination.
- Whether the cutting motor's +24V is the same rail as the board logic's +24V input, or a separate supply, is assumed (same rail) but not confirmed.
- ~~Heltec board's "5V" header pin accepting external input~~ **RESOLVED** - confirmed from the real Heltec V4 pin-map image ("Ve", J2 pins 3/4, documented external-supply input).
- ~~Relay footprint not assigned~~ **RESOLVED** - Songle SRD-24VDC-SL-C, both contacts broken out to J9 (see above).
- ~~No routing yet~~ **RESOLVED** - board is fully placed and routed, see "Mainboard PCB Placement" below. Ready to order.

## Mainboard PCB Placement

**Final state: placement and routing complete, board ready to order.** After an early auto-generated layout and a full reset forced by the DevKitC-1 core swap (wide-spaced 380x335mm starting layout, deliberately loose so parts were easy to grab and rearrange by hand), we placed every component and routed the whole board by hand in the KiCad GUI, including a back-layer GND copper pour (`back_gnd` zone). **Final board outline: 180.5x114mm** - shrunk down once the layout was arranged compactly, nowhere near the original wide-spaced 380x335mm placeholder size. 2-layer board (F.Cu/B.Cu), track widths 0.2-1.5mm and drill sizes 0.3-3.2mm, both comfortably within any standard fab's capabilities.

**K1 (relay) is fully wired, not a placeholder** - see the relay section above for why both contacts route out separately instead of picking one. The schematic symbol's IEC-style pin names (A1/A2/11/12/14) don't match the real footprint's plain numbered pads (1-5), so this needed an explicit pin-number translation for this one part - every other component's schematic pin numbers and footprint pad numbers already happen to match directly.

**J4 (HX711 header) went through a real footprint change late in the process** - originally a JST-XH cable connector, changed to a `PinSocket_1x04_P2.54mm_Vertical` socket for flat, direct-plug mounting (see "Mainboard PCB" above), with the pinout reversed to match the module's real mounted orientation. Swapping a connector's footprint (different pad pitch/geometry) invalidates any already-routed copper near it even when the net list itself doesn't change - this happened here (2 existing traces went dangling, needed re-routing) and is worth remembering for any future footprint swap on a partially-routed board.

**Pre-order sanity check (2026-08-16) caught one real omission:** R31, the e-stop pull-up resistor, existed in the schematic but had no footprint on the PCB at all (see the winchman-remote section above) - found via a schematic-vs-PCB reference cross-check, fixed by placing it against an already-existing (but previously dangling) `+3V3` stub trace and routing its other pin to the `ESTOP_SENSE` net. This is the kind of omission that a clean ERC/DRC won't catch by itself, since a component that was never placed doesn't register as an "unconnected pad" - worth re-running this cross-check before ordering any future revision of this board too.

**Final verification: ERC 0 violations, DRC 0 real violations** (1 cosmetic silkscreen-text overlap between U1's Value field and one of its own GPIO pin labels - visual only, no manufacturing or electrical impact). All 4 mounting holes present, no duplicate reference designators, no orphaned/missing footprints, no DNP components.

## Open Items

- Fardriver driverless/VCU CAN frame spec: **RESOLVED** - full CAN61 protocol document obtained from Fardriver support (see "Motor Controller" above). Still needs confirming against the real ND961200-CAN unit on the bench once hardware is in hand; analog throttle kept wired as the documented CAN-loss fallback either way.
- Final ESP32 carrier board choice: **RESOLVED** - plain ESP32-S3 N16R8 DevKitC-1 + external SN65HVD230 CAN transceiver, built into the mainboard PCB (see "Mainboard PCB" above). The earlier LilyGO T-2CAN / Waveshare ESP32-S3-POE-ETH-8DI-8DO candidates (from when 2 CAN buses were still assumed necessary) were not needed once the battery-CAN requirement was dropped.
- Winch-side LoRa: **RESOLVED** - Heltec WiFi LoRa 32 V4 (EU868, matching the pilot handheld's own Heltec board), wired to the mainboard as a UART peripheral via its real two-header (1x18+1x18) footprint (see "Mainboard PCB" above). A different, similarly-named Heltec module (HT-CT62) was briefly considered and rejected - different chip, ESP32-C3 not S3.
- Battery BMS architecture: **RESOLVED** - single ANT 30S BMS spanning both EEL boxes' cells (30 total, not 32) instead of two independent per-box BMS units in series (see "Battery" above). Tows-per-charge estimate still needs re-checking against the new cell count.
- Define the actual unified command/telemetry frame format (fields, encoding) shared by the GIGA UART link and the pilot LoRa link.
- Choose and wire up a barometric sensor for the pilot handheld; decide how much the tree-height transition trusts the sensor vs. the manual button.
- **Mainboard PCB design is complete and ready to order** (see "Mainboard PCB Placement" above). No firmware exists yet - that's the next phase once the board is back and verified working. All other wiring diagrams (GIGA UI node, LoRa handheld/winch-side module) are still outstanding.

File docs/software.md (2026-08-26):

# Open Paraglider Tow Winch

# Software Architecture

Version 0.1 (first draft - ESP32 mainboard comms layer only, no PID/CAN control logic yet)

---

## Overview

Three firmware nodes, matching the hardware split in [electronics.md](electronics.md):

```
Load Cell ──▶ ESP32 (PID loop) ──CAN──▶ Fardriver Controller ──▶ QS165 Motor
                  │  ▲
              UART│  │UART
                  ▼  │
         Arduino GIGA R1 + Display        LoRa ◀────────────▶ LoRa
              (operator UI)          (winch-side Heltec)   (pilot Heltec)
```

- **ESP32 mainboard** (`firmware/esp32_mainboard/`) - the only node covered by this document's protocol definitions and the only one with firmware started so far. Runs the state machine and (eventually) the PID tension loop and CAN61 link to the Fardriver controller.
- **GIGA R1 + Display** - winch operator UI. Talks to the ESP32 over the `GIGA UART` link (hardware UART0, see "Transports" below). Full command surface, full telemetry. Its own firmware (`firmware/giga_display/`) has started - WiFi, SD card, dashboard sync and on-device settings editing are built (see "GIGA Display Firmware" below) - but the actual operator UI over the ESP32 link above (tension display, state/e-stop controls) isn't built yet.
- **Pilot's Heltec handheld** - talks to the ESP32 *indirectly*, via the winch-side Heltec LoRa module (itself just a UART-attached peripheral of the ESP32, see [electronics.md](electronics.md)'s LoRa section). Minimal command surface (deadman + tree-height button), reduced telemetry (status display only). Neither Heltec's firmware is started yet.

**Both links carry the same JSON protocol** (same message types, same field names) - this is a deliberate design decision carried over from [electronics.md](electronics.md#unified-operator-command-protocol): the ESP32 parses one protocol regardless of which link a message arrived on, rather than maintaining two separate command sets. A message's `src` field (see below) tells the ESP32 which device sent it, which is what actually gates which command fields are honored - not which physical UART it arrived on.

---

## Transports

| Link | ESP32 pins | Arduino object | Notes |
|---|---|---|---|
| GIGA UART | GPIO43 (U0TXD) / GPIO44 (U0RXD) | `Serial0` | Hardware UART0. **Gotcha:** on the ESP32-S3 Arduino core, `Serial` defaults to the native USB-CDC port (GPIO19/20, the DevKitC-1's own USB-C), not this UART - use `Serial0` explicitly for this link, and reserve plain `Serial` for USB debug output only. Don't let the two get mixed up. |
| Heltec (winch-side) UART | GPIO14 (TXD) / GPIO21 (RXD) | `Serial1` | Bridges to the Heltec's own U0TXD/U0RXD (see [electronics.md](electronics.md)'s LoRa section) - the Heltec re-transmits whatever it receives here over LoRa to the pilot's matching Heltec, and forwards whatever it receives over LoRa back over this same UART. The ESP32 firmware doesn't need to know anything about LoRa itself, only that this UART is slower and lossier than the GIGA link. |

**Framing:** one **compact (no whitespace) JSON object per line**, terminated with `\n`. Baud rate 115200 on both links (the Heltec link is bandwidth-limited by the LoRa hop behind it, not by this UART - 115200 just needs to comfortably outrun the LoRa air rate, not match it).

**Why JSON, not a packed binary frame:** this is a human-interaction link (button presses, a display refreshing a few times a second), not the CAN61 link's 20ms real-time control loop - there's no tight timing budget to justify binary framing's added complexity. JSON is trivially debuggable from a serial monitor, which matters a lot for a first version. Revisit only if LoRa airtime/duty-cycle limits become a real constraint once tested on real hardware.

---

## Message Types

Every message has a `type` field that's either `"cmd"` (host -> ESP32) or `"telemetry"` (ESP32 -> host), plus a monotonically increasing `seq` (per-sender counter, wraps at 65535) so a receiver can notice dropped or out-of-order messages.

### `cmd` - host to ESP32

```json
{"type":"cmd","seq":42,"src":"giga","deadman":true,"tree_height":false,"state_cmd":"start_tow","tension_setpoint_kg":70,"fault_reset":false,"operating_mode":"winchman","pilot_name":"Jane Doe","pilot_weight_kg":85,"use_saved_calibration":false,"cal_raw_zero":123456,"cal_raw_100kg":234567,"under_tree_height_reduction_pct":40,"start_reduction_pct":20,"treeheight_to_full_tow_ramp_s":3,"start_to_treeheight_ramp_s":2,"release_before_taking_in_s":5,"pid_kp":1.2,"pid_ki":0.05,"pid_kd":0.01}
```

```json
{"type":"cmd","seq":103,"src":"handheld","deadman":true,"tree_height":false,"lat":47.123456,"lon":8.123456,"baro_alt_m":42.3}
```

| Field | Type | Sent by | Meaning |
|---|---|---|---|
| `type` | `"cmd"` | both | message discriminator |
| `seq` | uint16 | both | per-sender sequence counter |
| `src` | `"giga"` \| `"handheld"` | both | **which device sent this** - the ESP32 uses this to decide which of the fields below it's allowed to act on (see "Field authority" below), not which UART it arrived on |
| `deadman` | bool | handheld | pilot is actively holding the deadman control. Safety-critical - see "Deadman timeout" below |
| `tree_height` | bool | handheld | pilot has manually signalled "above tree height" - one-shot trigger, commits the ramp to the selected tow profile (see [control_philosophy.md](control_philosophy.md#launch-philosophy)) |
| `lat` / `lon` | number, optional | handheld | pilot's GPS position, sent every 2-5s - **log-only**, relayed straight into `telemetry` for the GIGA to write to its SD card (see "GPS + Logging" below and [electronics.md](electronics.md)'s note that GPS is never part of the safety trigger). Both must be present together or neither is applied |
| `baro_alt_m` | number, optional | handheld | pilot's barometric height above launch, sent alongside `lat`/`lon` - same log-only relay, **not** used for the tree-height trigger itself (that stays the manual `tree_height` button plus, eventually, the handheld's own local auto-trigger logic - see [electronics.md](electronics.md)'s barometric-height reasoning) |
| `state_cmd` | string, optional | giga | requested state-machine transition: `"calibrate"` (`IDLE`->`CALIBRATING`), `"calibration_done"` (`CALIBRATING`->`READY`, operator confirms the 100kg reference pull is done - see [control_philosophy.md](control_philosophy.md#calibrating)), `"start_tow"`, `"release"`, `"reset_fault"` (clears a latched fault **or** `EMERGENCY_STOPPED`, both return to `IDLE`), `"idle"`, `"emergency_stop"` (operator-triggered e-stop from GIGA - in addition to, not instead of, the mainboard's own local hardware e-stop switch, which forces this transition regardless of what any link is saying). Absent/omitted = no transition requested this message. **`"release"` can also be requested locally** by a physical switch on the winchman remote (see [electronics.md](electronics.md)), independent of this link entirely |
| `tension_setpoint_kg` | number, optional | giga | desired tow force, `TOW_FORCE_MIN`-`TOW_FORCE_MAX` kg (see `config.py`). A **numeric override**, not a named profile - profile-name-to-kg resolution, if wanted, happens in the GIGA's own UI, not on the wire (kept simple for this first version) |
| `fault_reset` | bool, optional | giga | acknowledge/clear a latched fault |
| `operating_mode` | `"solo"` \| `"winchman"`, optional | giga | set once at boot (see "Boot Configuration" below) - whether a winchman is operating the GIGA or the pilot is flying solo |
| `pilot_name` | string, optional | giga | set at boot, and again after every tow ends in `"winchman"` mode (see "Boot Configuration" below) - the current pilot's name, for tow-log administration (e.g. towing students with a winchman). Entered live on the winchman controller (GIGA touchscreen) at the winch, per tow - not something to prepare ahead of time elsewhere |
| `pilot_weight_kg` | number, optional | giga | set at boot, and again after every tow ends in `"winchman"` mode (see "Boot Configuration" below) - the current pilot's weight. Same live-at-the-winch entry as `pilot_name` |
| `use_saved_calibration` | bool, optional | giga | GIGA boot-UI switch, **default off** - when true (together with `cal_raw_zero`/`cal_raw_100kg`), skips the mandatory live `CALIBRATING` cycle and trusts the saved values instead. See "Boot Configuration" below |
| `cal_raw_zero` / `cal_raw_100kg` | integer, optional | giga | the saved two-point calibration reference (raw load-cell counts at 0kg and 100kg) from the GIGA's config file, only applied when `use_saved_calibration:true` |
| `under_tree_height_reduction_pct` / `start_reduction_pct` | number, optional | giga | tow-config tunables from the GIGA's SD-card config file - force reduction percentages for the under-tree-height and start phases. Not yet acted on by the control loop (see "Current Firmware Status") |
| `treeheight_to_full_tow_ramp_s` / `start_to_treeheight_ramp_s` | number, optional | giga | tow-config tunables - ramp durations between phases. Not yet acted on |
| `release_before_taking_in_s` | number, optional | giga | tow-config tunable - delay after release before the drum starts taking in rope. Not yet acted on |
| `pid_kp` / `pid_ki` / `pid_kd` | number, optional | giga | tow-config tunables - tension PID gains. Not yet acted on (no PID loop implemented yet) |

**Field authority (enforced on the ESP32, not just documented) - symmetric, each `src` is restricted to its own fields:**
- `src:"handheld"` can only affect `deadman`, `tree_height`, `lat`, `lon` and `baro_alt_m` - every GIGA-only field below is silently ignored if present with that `src`, even if the handheld's own firmware never sends them.
- `src:"giga"` can only affect `state_cmd`, `tension_setpoint_kg`, `fault_reset`, `operating_mode`, `pilot_name`, `pilot_weight_kg`, `use_saved_calibration`, `cal_raw_zero`, `cal_raw_100kg`, and the tow-config tunables above - `deadman`/`tree_height`/`lat`/`lon`/`baro_alt_m` from GIGA are likewise ignored, since those fields are meant to be the pilot's own live signal; letting the operator's UI set them too would defeat the point of the deadman check.

This is the wire-level version of the hardware design's own principle (see [electronics.md](electronics.md)'s winchman-remote section) that the pilot's remote gets a deliberately minimal, hard-to-misuse command surface - the ESP32 must not trust the far end's own firmware to self-restrict, since a link (LoRa especially) can be spoofed, glitched, or simply running old/buggy firmware.

### `telemetry` - ESP32 to host

```json
{"type":"telemetry","seq":1337,"state":"NORMAL_TOW","tension_kg":68.4,"tension_setpoint_kg":70,"rope_out_m":210.5,"rpm":842,"motor_current_a":38.2,"fault":false,"fault_code":0,"line_cut":false,"cal_valid":true,"boot_configured":true,"operating_mode":"winchman","pilot_name":"Jane Doe","pilot_weight_kg":85,"tow_config_loaded":true,"lat":47.123456,"lon":8.123456,"baro_alt_m":42.3}
```

| Field | Type | Meaning |
|---|---|---|
| `type` | `"telemetry"` | message discriminator |
| `seq` | uint16 | per-sender sequence counter |
| `state` | string | current state machine state - one of `IDLE`, `CALIBRATING`, `READY`, `LAUNCH`, `UNDER_TREE_HEIGHT`, `NORMAL_TOW`, `PAY_OUT`, `RELEASE`, `RECOVERY`, `EMERGENCY_STOPPED` (see [control_philosophy.md](control_philosophy.md#state-machine)) |
| `tension_kg` | number | measured tow force (load cell) |
| `tension_setpoint_kg` | number | current PID setpoint (may differ from what GIGA last requested, e.g. mid-ramp) |
| `rope_out_m` | number | estimated rope paid out (derived from hall sensors + drum diameter estimate) |
| `rpm` | number | drum RPM (from hall sensors) |
| `motor_current_a` | number | realized motor current, once the CAN61 telemetry frame is wired up - `0` / stale until then |
| `fault` | bool | true if a fault is latched |
| `fault_code` | integer | 0 = no fault; specific codes to be enumerated once fault handling is implemented |
| `line_cut` | bool | true if either line-cut switch has fired (informational - the relay itself fires in hardware regardless of firmware, see [electronics.md](electronics.md)'s line-cut section) |
| `cal_valid` | bool | true once a `CALIBRATING` cycle has completed successfully this session, **or** once a saved calibration has been loaded via `use_saved_calibration` (see [control_philosophy.md](control_philosophy.md#calibrating) and "Boot Configuration" below) - lets a display warn the operator if a tow is attempted before calibration is valid |
| `boot_configured` | bool | true once `operating_mode`, `pilot_name` and `pilot_weight_kg` are all set (see "Boot Configuration" below) - false blocks `calibrate`, so this tells the GIGA UI whether it still needs to prompt for them. In `"winchman"` mode this can go false again mid-session, after a release/fault clears `pilot_name`/`pilot_weight_kg` for the next pilot |
| `operating_mode` | `"solo"` \| `"winchman"` | the currently-set operating mode - `"winchman"` (the safe default) until the GIGA sets it |
| `pilot_name` | string | the currently-set pilot's name - empty whenever unset (at boot, or after a release/fault in `"winchman"` mode) |
| `pilot_weight_kg` | number | the currently-set pilot weight - `0` whenever unset (at boot, or after a release/fault in `"winchman"` mode) |
| `tow_config_loaded` | bool | true once the GIGA has sent at least one of the tow-config tunables (ramp/reduction/PID fields above) this power-up - lets the GIGA UI confirm its SD-card config actually made it across |
| `lat` / `lon` / `baro_alt_m` | number, optional | the handheld's last-known position/height, passed straight through from its own `cmd` messages (see above) - **omitted entirely** until the handheld's first fix arrives, rather than sending misleading `0,0` |

**Both links receive the exact same telemetry message** - the handheld's own display firmware just picks out the few fields it has room to show (state, tension, fault); it doesn't get a trimmed-down message. Simpler than maintaining two telemetry shapes, and the message is small enough that this isn't a real bandwidth concern at a 1-5 Hz telemetry rate.

**Send rate:** telemetry is broadcast periodically (both links, currently every 200ms in the firmware skeleton - i.e. 5 Hz) rather than only in response to a request. Commands are sent whenever the sender has something new to say (a button changed state) rather than polled.

---

## Deadman Timeout

The handheld's `deadman` field is the pilot's live "I'm still holding this" signal. The ESP32 tracks the time since the **last valid `cmd` with `src:"handheld"`** was received, regardless of what `deadman` was set to in it. If nothing arrives for **`HANDHELD_TIMEOUT_MS`** (firmware constant, currently 1000ms - conservative first guess, not yet tuned against real LoRa latency/loss behavior), the ESP32 treats this exactly like `deadman:false` - i.e. **link loss looks the same as the pilot letting go**, deliberately, since from a safety standpoint an unreachable pilot should never be treated as a "keep towing" signal by omission.

**The GIGA link has no equivalent timeout requirement** - by design (see [electronics.md](electronics.md)'s Overview), the GIGA is a UI node kept out of the actuation loop, so its own link dropping doesn't change what the PID/state-machine authority does. Losing the GIGA link just means the operator stops seeing telemetry until it reconnects.

**Open design note, not yet implemented (handheld/Heltec firmware hasn't been started at all):** in `"winchman"` mode, the handheld is carried by the student being towed, but the **winchman**, not the student, holds tow authority (calibrate/release/etc. are GIGA/winchman-only regardless of mode - see "Boot Configuration" above). So the plan is for the handheld's own firmware to disable `deadman` and its other buttons (inert - a press does nothing) whenever it knows it's in `"winchman"` mode, since a student shouldn't need to understand or operate them. **Crucially, `lat`/`lon`/`baro_alt_m` reporting must keep going on schedule regardless of that button-disable** - those aren't coupled to `deadman`/button state, and if the handheld firmware naively silenced its whole `cmd` stream along with the buttons, the tow would lose its GPS/height log entirely (see "GPS + Logging" below). This also means whatever eventually consumes `effectiveDeadman()` in the real actuation loop (still unimplemented - see "Current Firmware Status") **must not** treat an inert winchman-mode handheld's permanent `deadman:false` as "pilot let go" the way it correctly does for a real solo-mode timeout - the deadman safety-gate as designed only makes sense in `"solo"` mode, where the handheld's button really is the sole safety authority.

---

## Boot Configuration

Every power-up, the ESP32 starts with `operating_mode` defaulted to `"winchman"` and `pilot_name`/`pilot_weight_kg` unset (empty / `0`) - none of the three is persisted across a reboot, on purpose: stale settings from a previous day or a different pilot must never carry over silently.

`IDLE` is **locked** until the GIGA has actively sent `operating_mode`, `pilot_name` and `pilot_weight_kg` at least once this session - `state_cmd:"calibrate"` is refused otherwise. This forces the operator to deliberately (re-)confirm all three at the start of every session before a tow can proceed, rather than trusting a default. `pilot_name`/`pilot_weight_kg` are entered live on the winchman controller (GIGA touchscreen) at the winch, per tow - deliberately not something a separate prep tool (e.g. the home MQTT dashboard) can set ahead of time, since they change with whoever's flying next:

- `operating_mode: "winchman"` - the normal case, a winchman operates the GIGA at the winch. `calibrate`/`calibration_done` stay GIGA-only, matching the real-world radio procedure: the pilot at the start location requests calibration by radio, the winchman triggers it.
- `operating_mode: "solo"` - reserved for flying alone, where the pilot launches from a start location up to ~1km from the winch with nobody there to operate the GIGA. Not yet wired into any different authority behavior (`calibrate` is still GIGA-only regardless of mode) - see [firmware/esp32_mainboard/esp32_mainboard.ino](../firmware/esp32_mainboard/esp32_mainboard.ino)'s `OperatingMode` enum, which exists but isn't read anywhere yet. Whether/how `SOLO_TOW` should let the handheld trigger `calibrate` directly is still an open design question.

Check `telemetry`'s `boot_configured` field to know whether the GIGA still needs to prompt the operator for these before a tow can start.

**Per-tow pilot reset, `"winchman"` mode only:** after every `release` (successful tow end, from either the GIGA's `state_cmd` or the physical release switch - see [electronics.md](electronics.md)) or `emergency_stop`/local e-stop, the ESP32 forgets both `pilot_name` and `pilot_weight_kg` again - `boot_configured` goes back to `false` and `calibrate` is refused until the GIGA sends them once more. This forces the winchman to actively (re-)confirm who's flying and their weight for the next tow, rather than silently reusing the previous pilot's info - `pilot_name` matters here for tow-log administration when towing students with a winchman present, same reasoning `pilot_weight_kg` already had for the tow-force calc. **In `"solo"` mode this reset is skipped** - it's the same pilot for the whole session, so both persist across repeat tows instead of forcing re-entry every time. `operating_mode` itself is never reset this way, only `pilot_name`/`pilot_weight_kg`.

**Saved calibration, `use_saved_calibration`:** a GIGA boot-UI switch, **default off**. Off (or omitted) leaves calibration exactly as before - `cal_valid` only becomes true after a live `calibrate`/`calibration_done` cycle this session, i.e. the daily 100kg proof-pull ritual (see [control_philosophy.md](control_philosophy.md#calibrating)) is mandatory. Switching it on and sending `cal_raw_zero`/`cal_raw_100kg` (the GIGA's saved values from a previous session's config file) marks `cal_valid` true immediately, skipping the live cycle entirely for that session. This was deliberately left as an operator choice rather than a firmware default either way - calibration dialing in takes real flights to trust, and the ritual is also a live proof-test of the line, not just a sensor recalibration.

**Tow-config tunables:** the GIGA can also push `under_tree_height_reduction_pct`, `start_reduction_pct`, `treeheight_to_full_tow_ramp_s`, `start_to_treeheight_ramp_s`, `release_before_taking_in_s`, and `pid_kp`/`pid_ki`/`pid_kd` at boot, read from its own SD-card config file rather than hardcoded in firmware - these values need real flight time to dial in, and a field-editable file beats a firmware reflash for that. `telemetry`'s `tow_config_loaded` confirms at least one arrived. **None of these are acted on by the control loop yet** - see "Current Firmware Status" below; they're captured now so the wire format and boot flow are ready ahead of that work.

---

## GPS + Logging

Per-tow logging is a **GIGA-side responsibility**, not the ESP32's - keeps the safety-critical control firmware untouched by any storage/filesystem code (SD card writes, FAT quirks, etc. all live on the GIGA, where a slow or hung write can't stall a live tow). The GIGA writes one JSON log file per tow (settings + a position/state/height/tension entry every 2-5s - `tension_kg`, same field name and meaning as `telemetry`'s own, added once the MQTT dashboard's tow-detail chart wanted it in its hover tooltip - see "MQTT Dashboard" below) plus a separate persistent config file (the calibration reference and tow-config tunables from "Boot Configuration" above) - both to its own SD storage, not defined further here since it's GIGA-firmware-internal, not part of the ESP32 wire protocol.

What *is* part of this protocol: the ESP32 relays the handheld's `lat`/`lon`/`baro_alt_m` (see the `cmd` table above) straight into every `telemetry` message, purely as a passthrough - it doesn't act on them itself. This is deliberate: GPS (and, eventually, a handheld barometer) is explicitly **log-only**, never part of the safety-critical tree-height trigger (see [electronics.md](electronics.md)'s barometric-height reasoning - GPS vertical accuracy doesn't reliably clear the accuracy target that decision was based on). The "winch position," logged once at boot, is expected to just be the handheld's own GPS fix at boot-time (procedure: power everything on together at the winch, capture the fix, then walk the handheld out to the start location) - so no separate GPS module is needed on the GIGA itself.

---

## MQTT Dashboard (Winch page)

Ahead of the GIGA hardware/firmware existing, a **"Winch" page** was built into our separate self-hosted home dashboard ([MQTT_Layout](https://github.com/netbox123/MQTT_Layout), a Vue 3 + Express project unrelated to this repo's own codebase) - a prep tool so calibration/tow-profile/PID values and past tow logs have somewhere to live and be reviewed before the GIGA firmware is written.

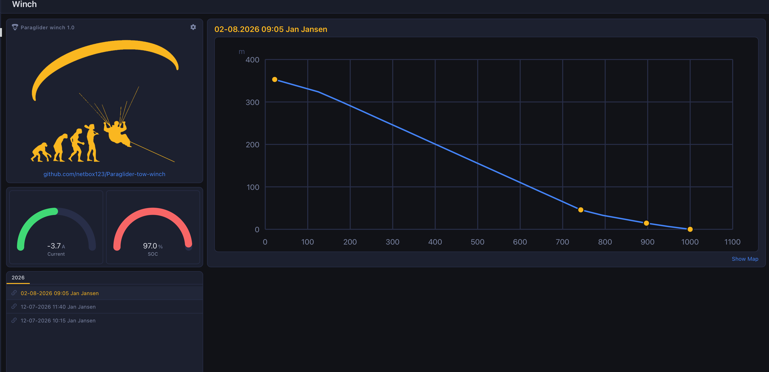
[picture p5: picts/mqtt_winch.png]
Winch page in the MQTT_Layout dashboard


- **About card** - logo, repo link, and a gear icon opening the **GIGA Boot Config** modal: every boot-config field from the "Boot Configuration" section above (`operating_mode`, calibration reference, tow-profile tunables, PID gains) except `pilot_name`/`pilot_weight_kg` - those two are entered live on the winchman controller itself, per tow, never prepared ahead of time here (see that section's reasoning). Persists to the dashboard's own `config/giga_boot_config.json`.

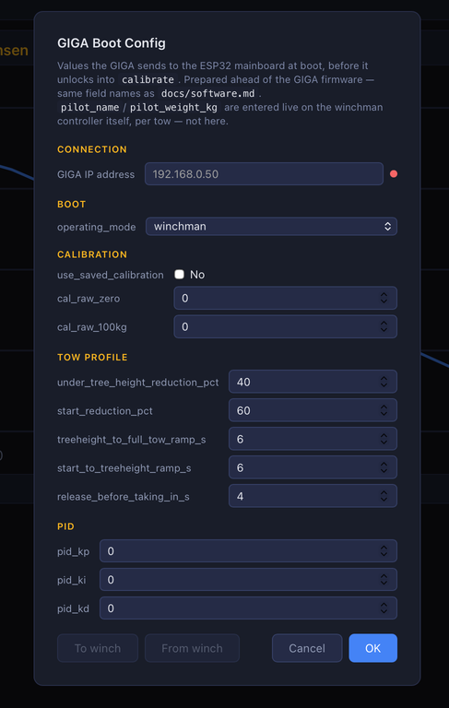
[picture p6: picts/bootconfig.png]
GIGA Boot Config modal
  

- **Battery gauges** - Current/SOC, wired to the site's existing MQTT topics.
- **Tow log** - a year-tabbed list of past tows plus a detail chart: height vs. **ground distance from the winch** (derived from `line_length_m` and height via Pythagoras, not time), release marked as the highest point, yellow dots at the state transitions (start, losing ground contact, normal tow starting, release), and a hover tooltip (state/height/distance/time-in-flight/`tension_kg`) with a crosshair, similar to Home Assistant's history graph. Currently showing placeholder tow records (`config/tows/*.json` in that repo) - no real tow has been logged yet since GIGA/handheld firmware doesn't exist.
- **GIGA sync ("To winch" / "From winch")** - confirmed working end-to-end against real GIGA hardware (see "GIGA Display Firmware" below): `GET /api/ping` and `GET`/`PATCH /api/config` are implemented on the GIGA and tested both directions (push an edited value, see it land on the GIGA's Tow Settings screens; edit on the GIGA, pull it back). `GET /api/tows` exists too but is still a `[]` stub - real tow-logging (position/height/tension written to the GIGA's SD card per tow) hasn't been built yet, so "From winch" always imports 0 tow records for now.

None of this lives in this repo - it's mentioned here because it defines a real contract (the GIGA-side HTTP API above) that the GIGA firmware will need to implement, and because the boot-config field set now has to stay in sync across three places: this document, `esp32_mainboard.ino`, and that dashboard's settings modal.

---

## GIGA Display Firmware

`firmware/giga_display/giga_display.ino` is the first real firmware for the GIGA node - same LVGL v9 stack as Arduino's own `LVGLDemo` example (`Arduino_H7_Video` + `Arduino_GigaDisplayTouch` + `lvgl`), landscape 800x480. What it covers so far is configuration and dashboard sync, not the actual winch/tow operator UI (see "Explicitly not yet implemented" below).

- **Homepage** - three mutually-exclusive states (idle / green nav menu / grey content screen), a gear icon opens the nav menu: **Network**, **Tow Profile**, **Calibration**, **PID**, **Cancel**. A small dot in the top-right corner shows live WiFi status (green/red), polled once a second independent of whatever screen is showing.
- **WiFi** - connects automatically at boot from `firmware/giga_display/secrets.h` (gitignored, `WIFI_SSID`/`WIFI_PASSWORD` need filling in locally, never committed), or manually via the Network menu (scan, pick from a list, on-screen-keyboard password entry, live `WiFi.begin()` status). Either path brings up the HTTP API below once connected.
- **SD card** - an external SPI reader wired to the GIGA's separate SPI1 header (`D89`/`D90`/`D91` + a `D10` CS pin, distinct from the board's main SPI pins - confirmed against a real GIGA on the Arduino forum, works with the plain `SD` library as-is). Holds one file, `/tow_config.json`, same field set as MQTT_Layout's `giga_boot_config.json`. Loaded at boot; rewritten whenever the config changes, from either the dashboard push or an on-device edit.
- **HTTP API** - implements the contract the MQTT Dashboard section above defines: `GET /api/ping`, `GET`/`PATCH /api/config`, `GET /api/tows` (`[]` stub for now - see above).
- **Tow Profile / Calibration / PID pages** - the boot-config tunables from "Boot Configuration" above, editable directly on the touchscreen and not just pushed from the dashboard, capped at 4 fields per page. Numeric fields use +/- stepper buttons rather than on-screen-keyboard typing; `operating_mode`/`use_saved_calibration` are single toggle buttons. Each page's Save button writes the whole config to SD and returns to the homepage in one tap - edits are already live over the HTTP API the moment they're made, Save only decides what survives a reboot.

---

## State Machine Reference

The ESP32 firmware's state enum matches [control_philosophy.md](control_philosophy.md#state-machine)'s finite state machine exactly: the linear sequence `IDLE -> CALIBRATING -> READY -> LAUNCH -> UNDER_TREE_HEIGHT -> NORMAL_TOW -> PAY_OUT -> RELEASE -> RECOVERY`, plus `EMERGENCY_STOPPED` - reachable from **any** of those states, never entered automatically as part of the normal sequence, and left only by an explicit `reset_fault` command (back to `IDLE`). See that document for what each state means and what it's allowed to do - this document only defines how state is *reported* and *requested* over the wire, not the transition logic itself (which lives in the firmware, not yet fully implemented - see "Current firmware status" below).

---

## Versioning

No explicit protocol-version field yet (v0.1 of this doc, first draft) - add one (e.g. `"proto":1`) before this protocol needs to support more than one firmware version talking to more than one other firmware version at a time. Not needed while every node's firmware is being written from scratch together.

---

## Current Firmware Status

**First step only - communications skeleton, not the control system.** `firmware/esp32_mainboard/esp32_mainboard.ino` implements:

- Both UART links (`Serial0` for GIGA, `Serial1` for Heltec), parsing/emitting exactly the `cmd`/`telemetry` messages defined above. The line-buffer per link is 512 bytes, sized for the wide boot-config push described below - a truncated line fails to parse silently, which would otherwise leave the boot-config lock stuck engaged with no obvious cause.
- The field-authority rule (handheld `cmd`s can only affect `deadman`/`tree_height`/`lat`/`lon`/`baro_alt_m`).
- The deadman timeout logic.
- Handheld `lat`/`lon`/`baro_alt_m` passthrough into every `telemetry` message (see "GPS + Logging" above) - real relay logic, the mainboard just never acts on the values itself.
- **`EMERGENCY_STOPPED`, `CALIBRATING` and the boot-configuration lock are real, guarded logic, not placeholders:**
  - The local hardware e-stop switch (`GPIO10`) is polled every loop and forces `EMERGENCY_STOPPED` unconditionally while held - independent of, and overriding, anything either UART link says. Leaving `EMERGENCY_STOPPED` requires an explicit `reset_fault`, and that's itself refused if the switch is still physically pressed.
  - `CALIBRATING` implements the real two-point sequencing from [control_philosophy.md](control_philosophy.md#calibrating): `calibrate` (only valid from `IDLE`) captures a tare reading, `calibration_done` (only valid from `CALIBRATING`) captures the second point and computes the counts-per-kg factor, setting `cal_valid`. Only the sensor input feeding this (`readLoadCellRaw()`) is still a stub returning `0` - the sequencing/validation around it is real and ready for when the HX711 is wired up.
  - `calibrate` is additionally refused until the GIGA has set `operating_mode`, `pilot_name` and `pilot_weight_kg` this power-up (see "Boot Configuration" above) - a real, enforced lock, not just documented intent. `pilot_name`/`pilot_weight_kg` are deliberately forgotten again after every `release`/`emergency_stop` in `"winchman"` mode (kept in `"solo"` mode), so this lock genuinely re-engages between tows, not just once per power-up.
  - `use_saved_calibration` + `cal_raw_zero`/`cal_raw_100kg` (GIGA-only, real logic): when set, marks `cal_valid` true immediately instead of requiring a live `CALIBRATING` cycle. Off by default - live calibration is unaffected unless the GIGA explicitly opts in.
  - The tow-config tunables (`under_tree_height_reduction_pct`, ramp times, PID gains) are captured into a real `TowConfig` struct and reported back via `tow_config_loaded` - but **not yet acted on** by any control logic, since that logic doesn't exist yet (see below).
  - A local physical **release** switch (`GPIO2`, the winchman remote's 7th pin, J8 - see [electronics.md](electronics.md), own dedicated pull-up resistor R35) requests `state_cmd:"release"` on a press, through the exact same guarded `requestStateTransition()` path the GIGA's own `"release"` command uses - lets the winchman end a tow cleanly even with the GIGA link dead, matching the e-stop switch's independence from both UART links.
  - The onboard RGB LED (`GPIO48`) reflects `state` in real time (see `updateStatusLed()`) - useful for bench testing without a display or Serial Monitor open; `EMERGENCY_STOPPED` blinks rather than staying solid.
  - The rest of the state machine (`start_tow`, `release`, `idle`) is still a bare placeholder transition, purely to have something real to show telemetry for - **not the real safety logic** (tree-height gating, force ramps, fault conditions beyond e-stop).
- Telemetry fields that don't have a real sensor behind them yet (`tension_kg`, `rope_out_m`, `rpm`, `motor_current_a`) are sent as `0`/placeholder so the message shape is stable and both display firmwares can be developed against it immediately, without waiting for the sensor/CAN work.

**Testing without real GIGA/Heltec hardware:** the firmware also accepts `cmd` lines typed into the USB Serial Monitor (debug console) and echoes `telemetry` there too, gated behind a `DEBUG_ACCEPT_SERIAL_COMMANDS` compile-time flag (on by default). This lets the whole protocol - state transitions, field authority, deadman timeout - be exercised from a single USB cable before either display firmware exists, by hand-typing lines like `{"type":"cmd","seq":1,"src":"giga","state_cmd":"calibrate"}`. Turn the flag off once real GIGA/Heltec firmware exists, so the debug console stops being able to act as a trusted command source.

**Explicitly not yet implemented (next steps, in roughly the order they unblock each other):**
- HX711 load cell reading (GPIO6/7) -> real `tension_kg`, and a real reading behind `readLoadCellRaw()` so calibration produces a real `countsPerKg` instead of always computing against a stubbed `0`.
- Hall sensor reading (GPIO41/42) -> real `rpm`/`rope_out_m`.
- The remaining safety-relevant state machine (tree-height force limiting, ramp rates, non-e-stop fault conditions) per [control_philosophy.md](control_philosophy.md) - e-stop and calibration are done, the rest of the sequence (`LAUNCH`/`UNDER_TREE_HEIGHT`/`NORMAL_TOW`/`PAY_OUT`/`RELEASE`/`RECOVERY`) is still bare placeholder transitions. This is also what will actually *use* the tow-config tunables (`under_tree_height_reduction_pct`, the ramp/release timings) - they're received and stored today but don't affect anything yet.
- PID loop (tension error -> torque setpoint) - same story, `pid_kp`/`pid_ki`/`pid_kd` are received but unused until this exists.
- Handheld GPS + barometer hardware itself isn't wired up yet (see [electronics.md](electronics.md)'s open items) - the `lat`/`lon`/`baro_alt_m` relay logic above is ready and waiting for real values.
- CAN61 TX/RX to the Fardriver controller (GPIO4/5) per [electronics.md](electronics.md)'s Motor Controller section - not yet confirmed against real ND961200-CAN hardware.
- Reading the mainboard's remaining local safety GPIOs (tension nudge switches, line-cut sense, relay drive) - direct GPIO, not part of this JSON protocol, but line-cut sense feeds into `telemetry`'s `line_cut` field once wired up. (E-stop, GPIO10, is now read for real - see above.)
- The Heltec firmwares (both winch-side and pilot-side) - not started.
- The GIGA's own operator UI (tension display, state-machine/e-stop controls, using the ESP32 `GIGA UART` link above) - not started; its WiFi/SD/dashboard-sync/settings firmware has (see "GIGA Display Firmware" above).
- Real per-tow logging on the GIGA (position/height/tension writes to the SD card, see "GPS + Logging" above) - `GET /api/tows` currently just returns an empty array.

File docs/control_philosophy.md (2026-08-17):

# Open Paraglider Tow Winch

# Control Philosophy

Version 0.2

---

## Design Goal

The objective of the tow winch is **not to control rope speed**.

The objective is to control **tow force**.

A skilled tow operator does not think in terms of rope speed. He constantly adjusts the throttle to maintain the correct pull on the pilot.

The electronic controller shall reproduce this behaviour.

---

# Primary Control Loop

The load cell is the primary control sensor.

The controller continuously compares:

Measured Tow Force

with

Desired Tow Force

The difference is processed by a PID controller.

The PID output is **motor current**.

Motor current produces motor torque.

Motor torque produces drum torque.

Drum movement is therefore a consequence of regulating tow force.

The controller never directly commands drum speed.

```
Desired Force
      │
      ▼
Compare with Load Cell
      │
      ▼
      PID
      │
      ▼
Requested Motor Current
      │
      ▼
Fardriver Motor Controller
      │
      ▼
QS165 Motor
      │
      ▼
Drum Torque
      │
      ▼
Tow Force
      │
      └───────────────┐
                      │
                 Load Cell
```

---

# Drum Behaviour

Three operating conditions naturally exist.

## Pull

Measured force is below the desired value.

The PID increases motor current.

Motor torque increases.

The drum pulls rope in.

---

## Hold

Measured force equals the desired value.

Motor torque balances rope tension.

The drum may rotate slowly or stop completely.

---

## Pay Out

Measured force exceeds the desired value.

The PID reduces motor current.

If required, motor torque becomes negative (or commands controlled payout depending on the motor controller).

The drum rotates forward.

The rope force decreases until the desired value is reached again.

This electronically replaces the force limiting behaviour that was previously obtained by modifying the slip characteristics of automotive torque converters.

---

# Sensors

## Primary Control Sensor

Load Cell

Purpose:

Close the force control loop.

This is the only sensor directly controlling the tow force.

---

## State Sensors

Hall sensors mounted on the drum provide machine state information.

Examples:

- Drum RPM
- Drum direction
- Rope payout
- Remaining rope
- Estimated drum diameter
- Estimated line speed

These sensors do **not** regulate tow force.

They inform the controller about the current operating condition.

---

# State Machine

The complete controller operates as a finite state machine.

Each state has its own preset parameters and safety limits.

Example:

```
IDLE

↓

CALIBRATING

↓

READY

↓

LAUNCH

↓

UNDER TREE HEIGHT

↓

NORMAL TOW

↓

PAY OUT

↓

RELEASE

↓

RECOVERY
```

**EMERGENCY STOPPED** is not part of the linear sequence above - it can be entered from **any** state, immediately, the moment an e-stop is triggered (local switch or operator command). It is a dead end, not a step: the system stays there, tow force released, until an operator explicitly clears it, and only then returns to `IDLE`. Nothing about it is time-based or automatic-recovery - see the [software.md](software.md) protocol doc for how a fault-reset command clears it.

The PID controller remains active in every state.

Each state modifies:

- Desired tow force
- Maximum motor current
- Maximum payout speed
- Force ramp rate
- Safety limits
- Allowed operator actions

The state machine determines *how* the system behaves.

The PID determines *how much motor current is required*.

---

# Calibrating

Every winch day should start with a short calibration step.

At the start location, the line is hooked to a calibrated electronic scale, and tension is raised to 100 kg.

This serves two purposes:

- The load cell is calibrated against a known reference force.
- The line itself is proof-tested to 100 kg, confirming it can safely take the force needed to get a pilot above tree height.

---

# Launch Philosophy

During launch and while the pilot is below tree height:

Maximum tow force shall be limited to just enough force to get the pilot into the air.

After the pilot is safely above tree height:

Tow force is smoothly ramped to the selected towing profile, approx pilot weight

No sudden increase in tow force is permitted.

---

# Design Philosophy

The system is fundamentally a **Tow Force Controller**.

The mechanics (motor, gearbox, drum and frame) provide the physical capability.

The load cell, PID controller and state machine provide the behaviour.

The objective is to reproduce the actions of an experienced human tow operator while providing repeatable, adjustable and predictable towing performance.

Design principle: Control force directly. Let speed be the result.

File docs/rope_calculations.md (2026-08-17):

# Open Paraglider Tow Winch

# Rope / Drive Train Calculations

Version 0.2

---

## Purpose

Estimate rope tension and rope speed available from the QS165 motor, through the internal gearbox and the 428 chain reduction, across the drum's full range of wound diameter.

This matters because the drum diameter is not constant: it grows from the bare core to the full flange diameter as rope winds on. Available torque at the rope is diameter-dependent even though the PID controller (see [control_philosophy.md](control_philosophy.md)) holds tow force constant within whatever range is actually available.

---

## Inputs

**Motor** (QS165 60H V3, "QSJ165A-60-10KW"). Figures below are for the motor's own output shaft, i.e. already after its internal 2.37:1 gearbox - this is the shaft the 14T sprocket sits on.

- Rated (continuous) speed: 2280 RPM
- Rated (continuous) power: 10,000 W
- Peak power (short bursts only): 20,000 W
- Max speed: 3165 RPM
- Max torque: 170 N·m

Sourced from QS Motor's own listings and retailers for this exact variant - the manufacturer's spec table is published as an image and could not be extracted directly, so treat these as approximate, not datasheet-certified.

**Chain reduction**: motor sprocket 14T, drum sprocket 76T -> ratio 76/14 = 5.4286

**Drum diameter** ([`config.py`](../freecad/config.py)): core 390 mm (empty) to flange 590 mm (full of rope). Radius 0.195 m to 0.295 m.

---

## Stall Tension (0 km/h)

Drum shaft torque = motor max torque x chain ratio = 170 x 5.4286 = **923 N·m**

Force = torque / drum radius:

| Drum state | Radius | Force |
|---|---|---|
| Core (empty) | 0.195 m | 4733 N = **483 kgf** |
| Flange (full) | 0.295 m | 3129 N = **319 kgf** |

Both far exceed `TOW_FORCE_MAX` (100 kg). This headroom is expected - the motor is not sized to run at its own limit, the PID loop limits actual tow force electronically.

---

## Maximum Rope Speed

Drum shaft max speed = motor max speed / chain ratio = 3165 / 5.4286 = 583 RPM = 61.05 rad/s

Rope speed = drum angular speed x radius:

| Drum state | Radius | Rope speed |
|---|---|---|
| Core (empty) | 0.195 m | 11.9 m/s = **42.9 km/h** |
| Flange (full) | 0.295 m | 18.0 m/s = **64.8 km/h** |

Maximum achievable rope speed itself depends on how much rope is wound on. A drum that starts a tow near-empty cannot reach 50 km/h until enough rope has wound back in to bring the effective diameter up to roughly 455 mm.

---

## Tension at 50 km/h

At 583 RPM (drum shaft), the motor is well above its rated 420 RPM (drum shaft rated speed = 2280 / 5.4286). Above rated speed the motor is power-limited, not torque-limited: available torque falls as speed rises to hold power constant.

Radius needed for 50 km/h (13.89 m/s) at max drum speed (61.05 rad/s): r = 13.89 / 61.05 = 0.2275 m (diameter ~455 mm - partway through a tow, not at a bare drum).

Torque = power / angular speed, at that operating point:

| Power basis | Torque | Force |
|---|---|---|
| Rated (continuous), 10 kW | 164 N·m | 720 N = **73 kgf** |
| Peak (short bursts), 20 kW | 328 N·m | 1440 N = **147 kgf**, not sustainable |

---

## Tension at 40 km/h (more realistic max, no wind)

50 km/h assumes still air; a more realistic no-wind maximum is closer to 40 km/h (13.89 -> 11.11 m/s). This case is meaningfully better than the 50 km/h figure because the torque/power-limited boundary depends on drum diameter, and 40 km/h falls on different sides of that boundary depending on how much rope is wound on.

Rated drum shaft speed (420 RPM) is reached, at 40 km/h, at a drum diameter of about **505 mm** - partway between core and flange.

| Drum state | Radius | Drum RPM | Regime | Force |
|---|---|---|---|---|
| Core (empty), Ø390mm | 0.195 m | 544 RPM | power-limited | 900 N = **92 kgf** continuous (184 kgf peak) |
| >Ø505mm (partway wound) | - | <420 RPM | full torque | **319 kgf** (same as stall) |
| Flange (full), Ø590mm | 0.295 m | 360 RPM | full torque | **319 kgf** |

So at 40 km/h, the full `TOW_FORCE_MAX` (100 kg) is available for most of the drum's fill range - only near a bare/empty drum does it drop, to about 92 kgf continuous, still close to the 100 kg target (and 184 kgf is available in short bursts even then).

---

## Sustained Stall / High-Wind Hold Margin

Wind at altitude can be stronger than at ground level. Since the winch controls tension, not drum speed (see [control_philosophy.md](control_philosophy.md)), the drum speed is whatever the wind and pilot's position demand - including, in strong/gusty conditions, dropping to zero or briefly reversing (paying out) to hold the tension setpoint.

Holding torque at zero RPM is harder on a PMSM than running under load: current concentrates continuously in whichever winding phases are aligned with the rotor's fixed position, instead of commutating evenly across all three phases while spinning. This is why continuous stall torque ratings are normally well below the dynamic/peak torque figure used above.

The reassuring part: holding `TOW_FORCE_MAX` (100 kg) at zero RPM only requires a fraction of the available stall torque (923 N·m at the drum, from the Stall Tension section above):

| Drum state | Max stall force | 100 kg as % of max |
|---|---|---|
| Core (empty) | 483 kgf | **20.7%** |
| Flange (full) | 319 kgf | **31.3%** |

So a sustained high-wind hold needs only about 21-31% of the motor's dynamic stall torque, depending on drum fill. That is a meaningful thermal margin, though it should still be checked against the motor controller's actual continuous-stall current/thermal-foldback rating (not yet found - the QS165 spec sheet publishes this as an image) before treating it as fully confirmed.

---

## Level Wind Synchronization Ratio

The level wind screw (`config.LEVELWIND_SCREW_LEAD` = 20 mm) is driven off the drum's own rotation through a 2-stage HTD-5M belt reduction via an idle jackshaft ([`main.py`](../freecad/main.py)): drum sprocket 50T -> jackshaft large pulley 100T -> (same shaft) jackshaft small pulley 40T -> screw sprocket 66T. The code comments this as "3.3:1 overall, validated on paper only so far" - checked here against the actual requirement.

**Required ratio:** for the rope to lay edge-to-edge with no gap or overlap, the carriage must travel exactly one rope diameter per drum revolution. With `ROPE_DIAMETER` = 3 mm and a 20 mm screw lead:

Required screw revolutions per drum revolution = 3 / 20 = 0.15, i.e. a **6.67 : 1** drum-to-screw ratio.

**Actual ratio, from the current sprocket/pulley teeth:**

ω_screw / ω_drum = (50/100) x (40/66) = 0.303, i.e. a **3.3 : 1** drum-to-screw ratio.

**Result: the current gearing turns the screw about 2.0x too fast relative to the drum.** At 3.3:1 the carriage moves ~6.1 mm per drum revolution against 3 mm of rope - each wrap would land with roughly a 3 mm gap next to the previous one instead of sitting flush, rather than the neat, tight winding this project targets.

This has not been built yet - the jackshaft/screw pulleys are still placeholder envelopes ("real HTD-5M pulley dimensions haven't been sourced yet" per the code comment) - so it's a design-stage finding, not a rebuild. One way to close the gap without touching the other two sprockets: reduce `JACKSHAFT_SMALL_PULLEY_TEETH` from 40T to ~20T (50/100 x 20/66 = 0.152, matching the 0.15 target almost exactly). Needs a decision before real pulleys are ordered.

---

## Implication

Stall force is comfortably more than needed (319-483 kgf available vs. 100 kg target), so launch force is not a concern.

50 km/h is a somewhat unrealistic worst case - a more realistic no-wind maximum is closer to **40 km/h**, and at that speed the full `TOW_FORCE_MAX` (100 kg) holds for most of the drum's fill range, only easing to about 92 kgf continuous (184 kgf peak) when the drum is nearly empty.

The 50 km/h figure is kept above as the theoretical worst case: **above roughly 31-47 km/h** (depending on drum fill - the speed at which the motor reaches its rated 420 RPM drum-shaft speed and becomes power-limited), sustained tow force does fall below 100 kg, reaching about 73 kgf continuous at 50 km/h. If a hard 100 kg-at-50km/h requirement ever matters, the drive train would need a larger reduction (more teeth on the drum sprocket, or a lower gearbox ratio) - at the cost of a lower maximum rope speed for the same motor RPM limit. Given real tows are closer to 40 km/h, this is not currently a practical concern.

---

*Every figure in this document assumes the 14T motor sprocket / 76T drum sprocket pair (5.4286:1 chain ratio). If the drum sprocket tooth count changes, all tension and speed numbers here need to be recalculated - they do not scale in an obvious way (tension scales up, speed scales down, and the torque/power-limited crossover points shift too). Also depends on [`config.py`](../freecad/config.py) (`GEARBOX_RATIO`, `DRUM_CORE_DIAMETER`, `DRUM_FLANGE_DIAMETER`) and the motor spec assumptions above.*

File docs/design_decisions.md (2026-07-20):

## Rope guide after the drum

Reason:

The rope enters from the right.

The drum is placed before the level-wind.

This maximizes the distance between drum and guide,
reducing the fleet angle and improving winding accuracy.

## Directional Safety

Maintaining the correct flight direction toward the winch is one of the pilot's primary responsibilities.

A pilot who flies away from the tow line experiences an increasing sideways component of the rope force.

As the angle increases:

- the lateral pull increases,
- the pilot must make larger steering corrections,
- recovery becomes progressively more difficult,
- the situation can rapidly become unstable.

An experienced tow operator recognizes this development early and immediately reduces the commanded tow force.

Reducing the tow force reduces both the forward and lateral rope forces, allowing the pilot to regain directional control.

If the deviation continues to increase, the tow shall be terminated.

---

## 90° Rule

If the pilot reaches approximately **90 degrees** from the intended tow direction, the tow line shall be cut immediately.

At this point the tow has become unsafe.

Continuing the tow can rapidly increase the danger to both the pilot and surrounding people.

The release decision is based on the operator's observation of the pilot and wing, not on the measured tow force.

Immediate release always has priority over completing the tow.

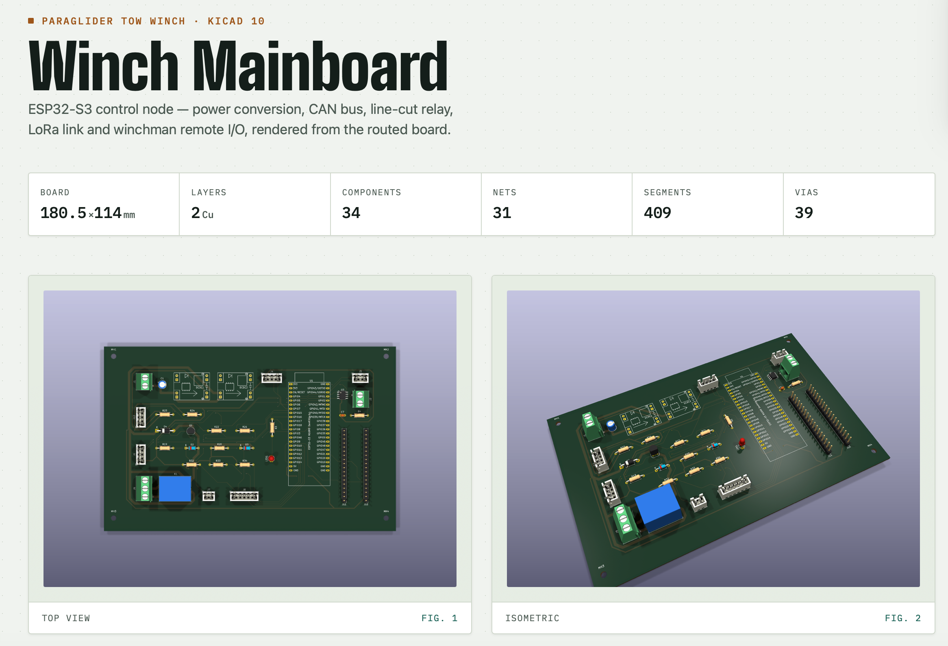
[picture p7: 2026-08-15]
kicad/winch_mainboard/pict/3d view.png

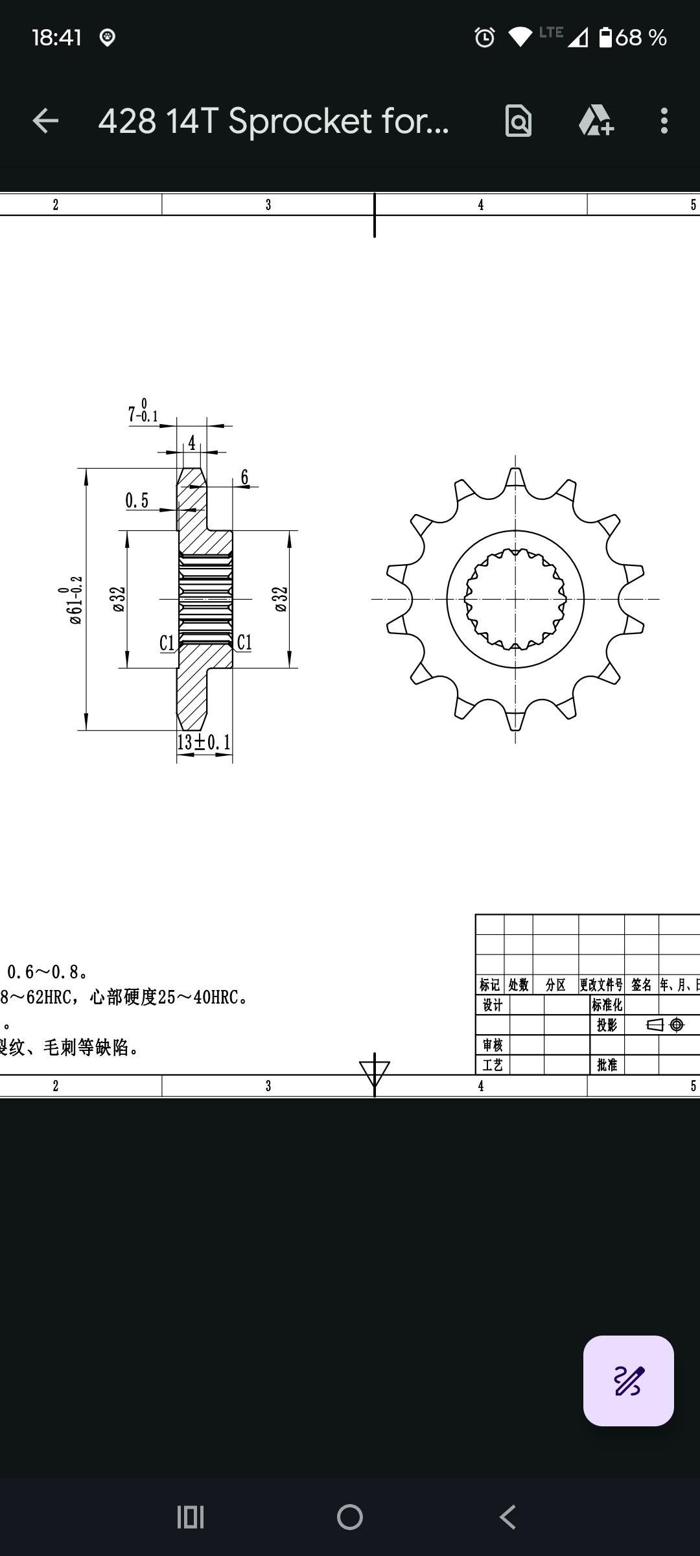
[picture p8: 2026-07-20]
freecad/drawings/428 14T sprocket.jpg

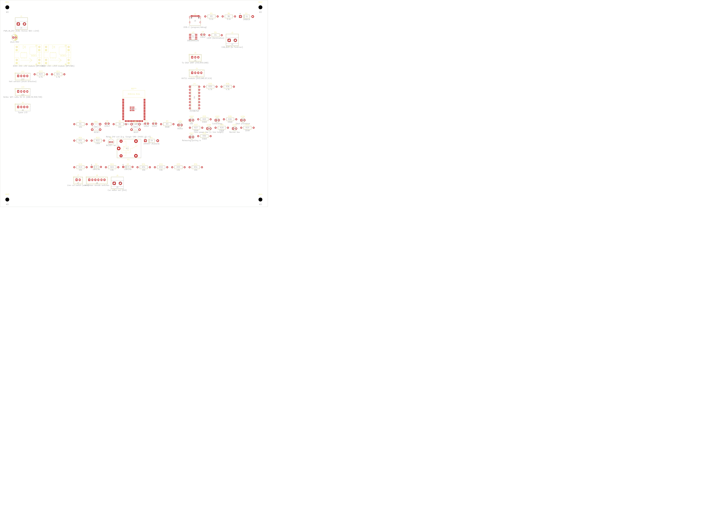
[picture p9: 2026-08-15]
kicad/winch_mainboard/winch_mainboard_top.png

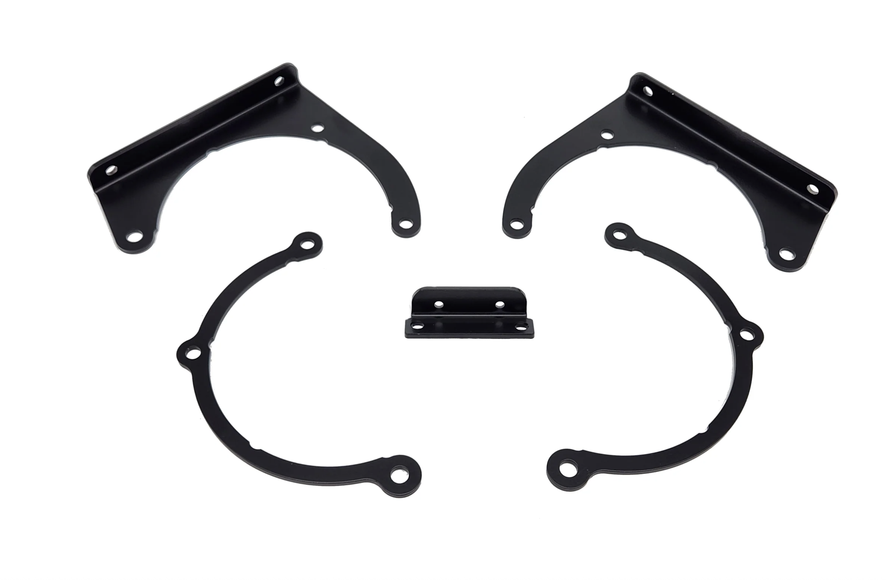
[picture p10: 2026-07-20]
freecad/drawings/qs165 motormount2.png

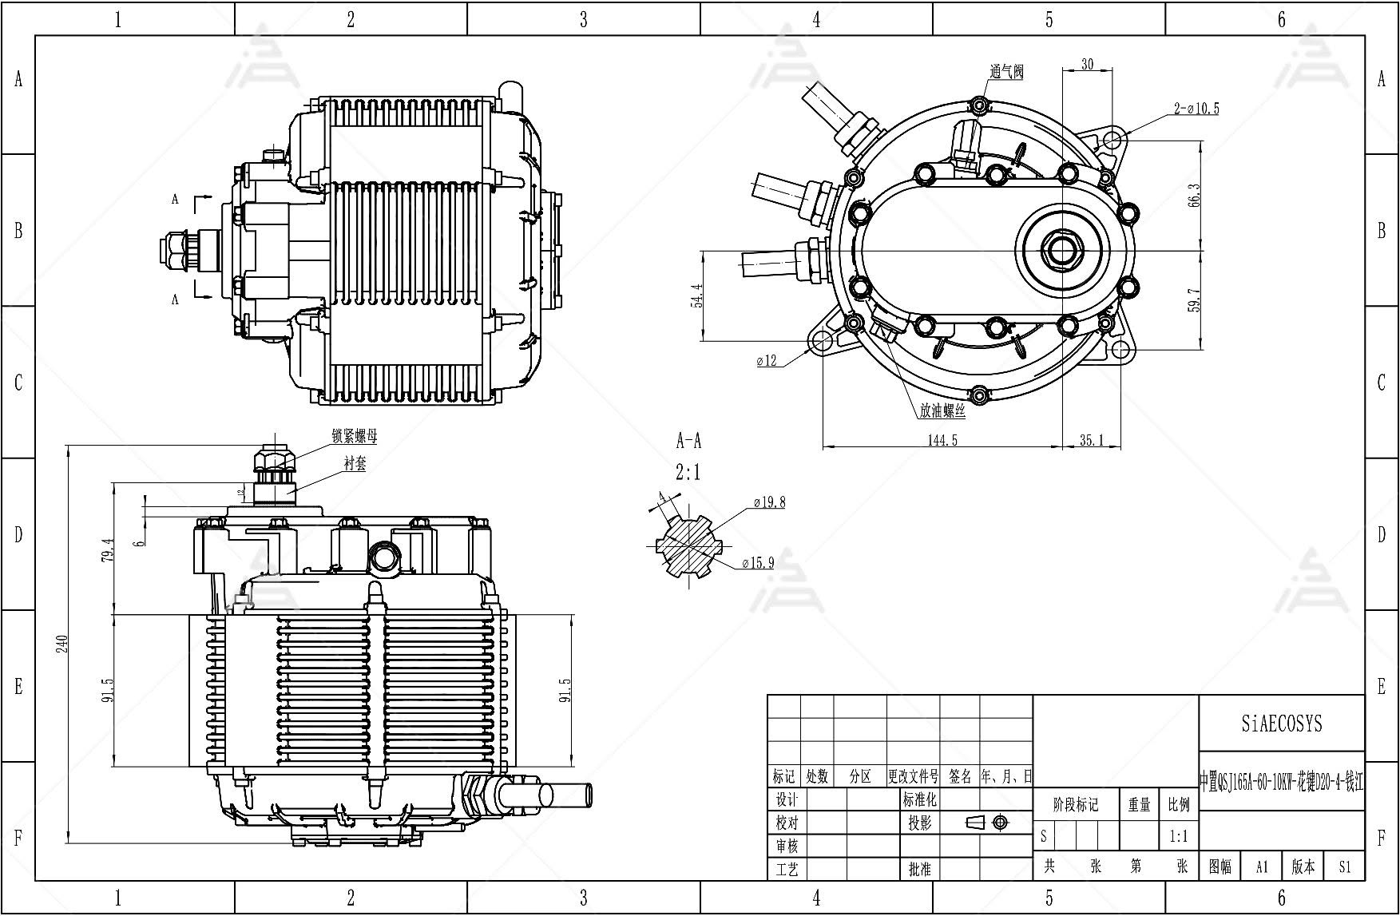
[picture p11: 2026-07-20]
freecad/drawings/qs165_60H.jpg

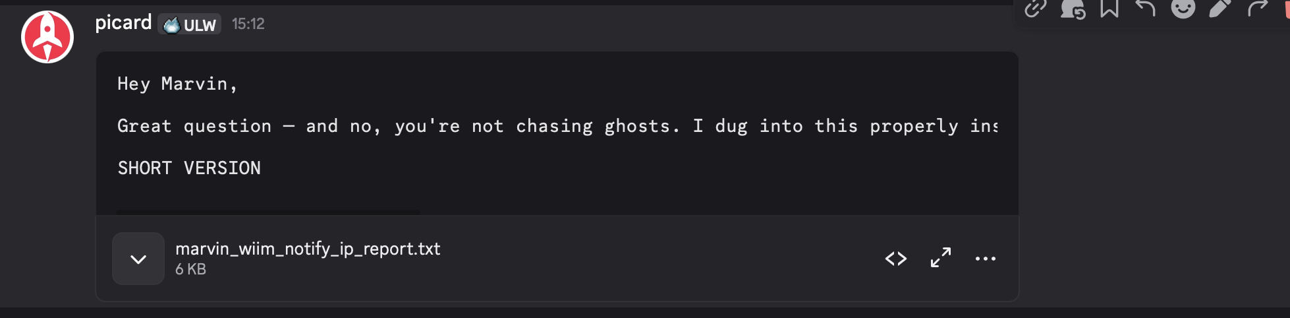
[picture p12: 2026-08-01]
picts/self-reversing-screw-3/Screenshot 2026-07-28 at 15.21.57.png

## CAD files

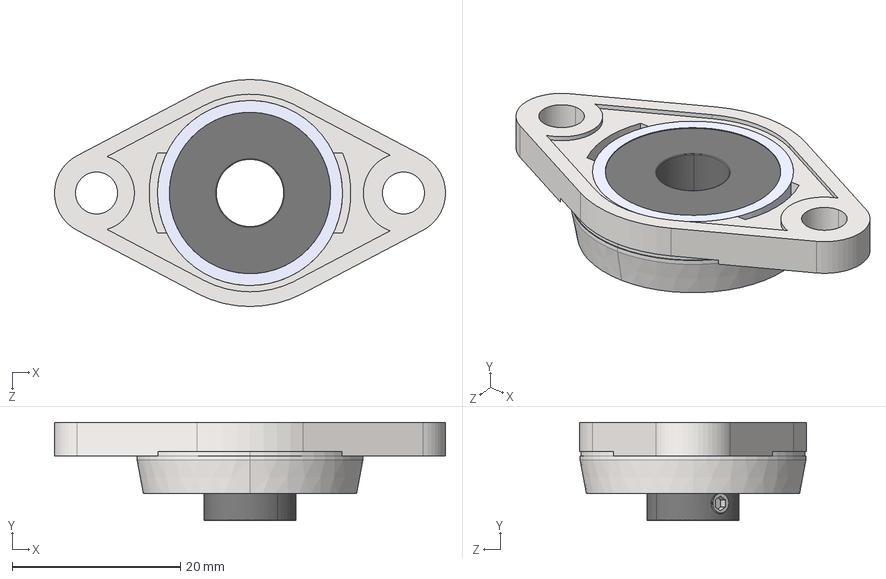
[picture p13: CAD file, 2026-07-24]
picts/flange bearing/ASSEMBLY OF KFL CASING AND BEARING.STEP
46.5 x 11.7 x 27.0 mm
FLANGE^KFL08
PART 1 BEARING
PART 2 BEARING
PART 3 BEARING x 7
GRUB M2.5 x 2

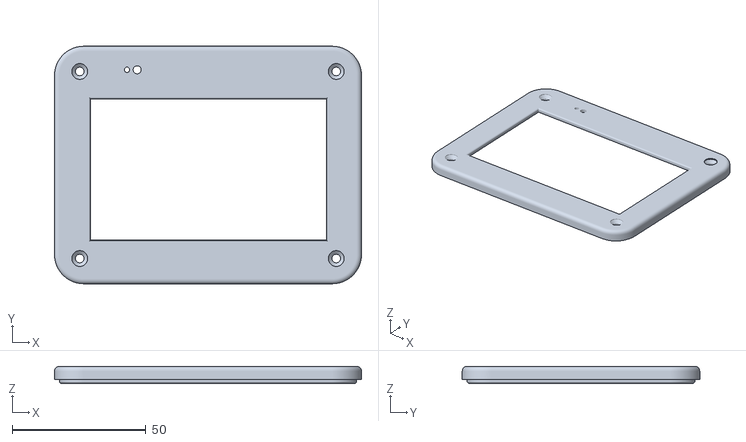
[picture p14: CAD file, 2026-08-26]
freecad/drawings/Giga display shield case top.stl
114.9 x 88.9 x 6.45

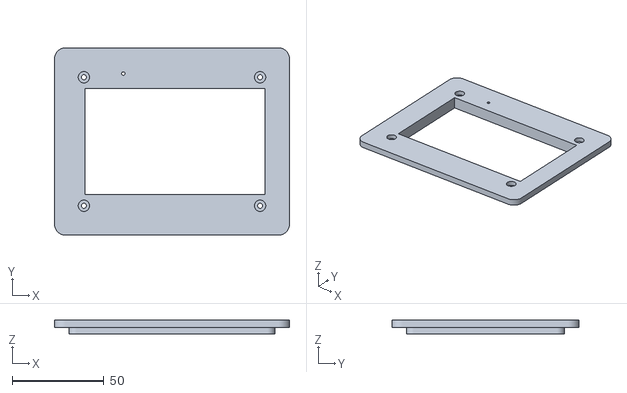
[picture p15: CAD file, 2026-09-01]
gigadisplay_holder/giga_display_frame.stl
128.0 x 102.0 x 7.50

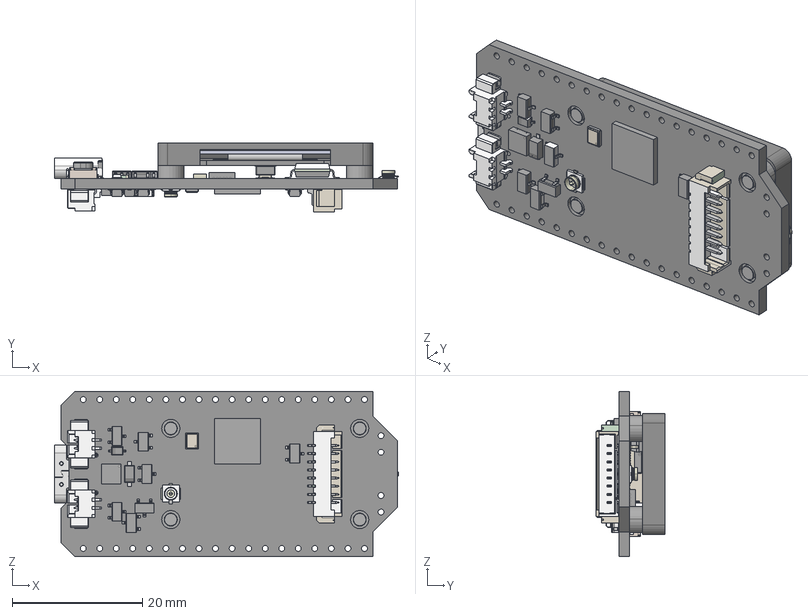
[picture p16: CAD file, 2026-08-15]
kicad/heltec/Heltec LoRa 32 V4.stp
52.8 x 10.7 x 25.4 mm
HTIT-WB32LAF_V4.2
HTIT-WB32LAF_V4.2 (4)
HTIT-WB32LAF_V4.2 (7)
HTIT-WB32LAF_V4.2 (127)
HTIT-WB32LAF_V4.2 (143)
HTIT-WB32LAF_V4.2 (157)
HTIT-WB32LAF_V4.2 (161)
HTIT-WB32LAF_V4.2 (176)
HTIT-WB32LAF_V4.2 (181)
HTIT-WB32LAF_V4.2 (200)
HTIT-WB32LAF_V4.2 (201)
HTIT-WB32LAF_V4.2 (216)
HTIT-WB32LAF_V4.2 (217)
HTIT-WB32LAF_V4.2 (284)
HTIT-WB32LAF_V4.2 (303)
HTIT-WB32LAF_V4.2 (306)
HTIT-WB32LAF_V4.2 (307)
HTIT-WB32LAF_V4.2 (308)
HTIT-WB32LAF_V4.2 (312)
HTIT-WB32LAF_V4.2 (315)
HTIT-WB32LAF_V4.2 (316)
HTIT-WB32LAF_V4.2 (317)
HTIT-WB32LAF_V4.2 (318)
HTIT-WB32LAF_V4.2 (319)
HTIT-WB32LAF_V4.2 (320)
HTIT-WB32LAF_V4.2 (766)
HTIT-WB32LAF_V4.2 (770)
HTIT-WB32LAF_V4.2 (774)
HTIT-WB32LAF_V4.2 (778)
HTIT-WB32LAF_V4.2 (794)
HTIT-WB32LAF_V4.2 (798)
HTIT-WB32LAF_V4.2 (970)
HTIT-WB32LAF_V4.2 (987)
HTIT-WB32LAF_V4.2 (988)
HTIT-WB32LAF_V4.2 (2110)
HTIT-WB32LAF_V4.2 (2196)
HTIT-WB32LAF_V4.2 (2214)
HTIT-WB32LAF_V4.2 (2324)
_5c_X_5c_C2_5c_X_5c_DD_5c_X_5c_D6_5c_X_5c_F9 x 4
M2_5c_X_5c_C2_5c_X_5c_DD_5c_X_5c_CB_5c_X_5c_BF x 4
HTIT-WB32LAF_0.96OLED_SSD1315_V0.5
B-PK-F
0.96 Lora 32-v4.2_5c_X_5c_C6_5c_X_5c_C1_5c_X_5c_C4_5c_X_5c_BB
HTIT-WB32LAF_0.96OLED_SSD1315_V0.5 (154)
view_area

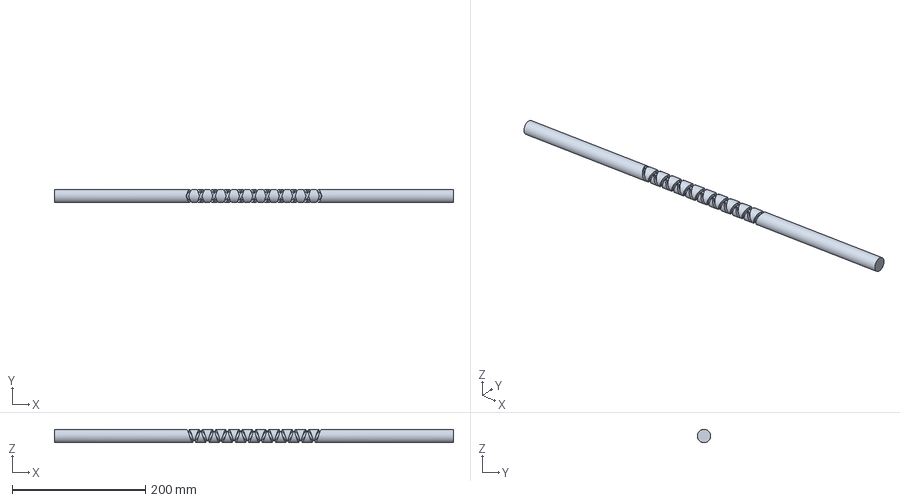
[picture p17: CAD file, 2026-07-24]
freecad/drawings/RS2020-200L600.stp
600.0 x 20.0 x 20.0 mm

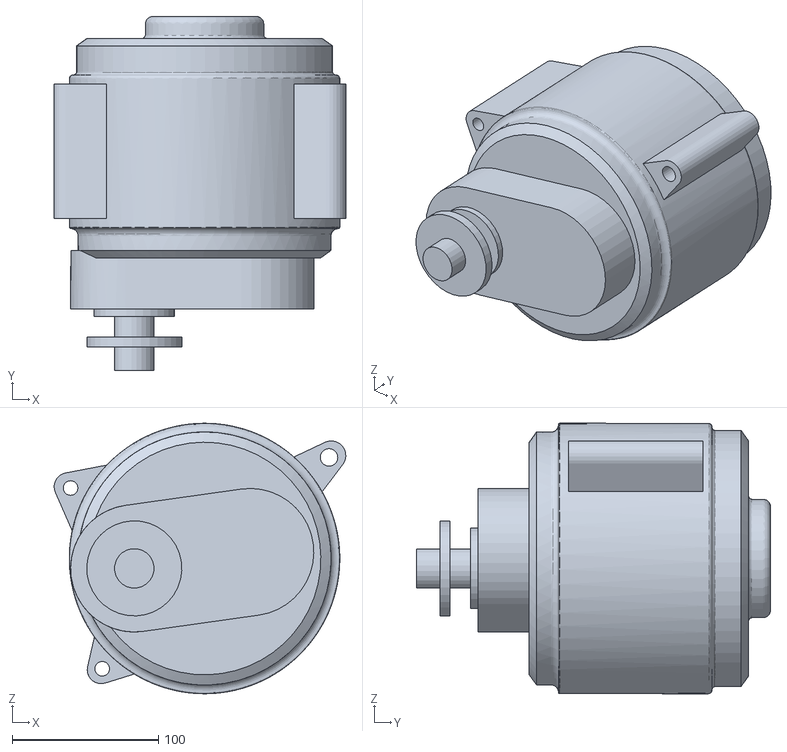
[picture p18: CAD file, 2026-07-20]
freecad/drawings/QSMotor_QS165_60H_v3.stl
199.4 x 242.0 x 185.0

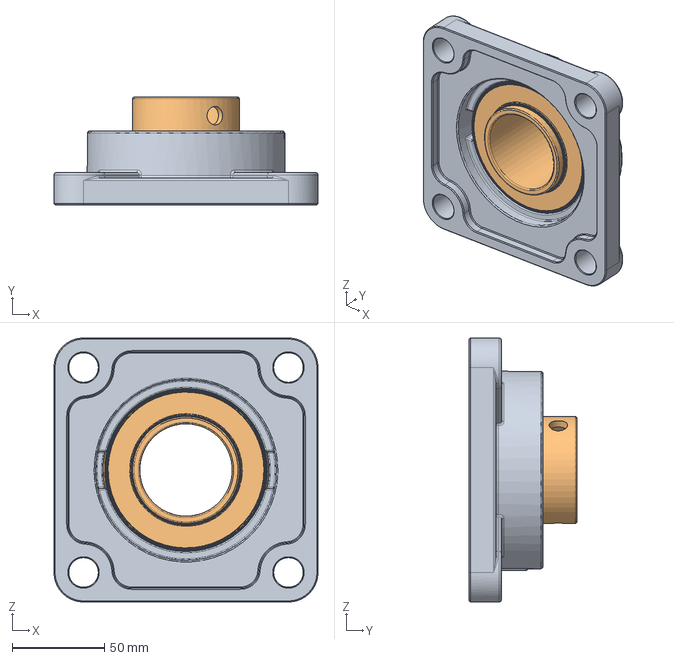
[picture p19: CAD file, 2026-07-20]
freecad/drawings/bearing50.stp
143.0 x 58.3 x 143.0 mm
SF-210_A
SUC-210

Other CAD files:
gigadisplay_holder/GigaDisplayHolder-GigaFrame.stl
gigadisplay_holder/GigaDisplayHolder.FCStd
picts/chain-n-428-cadena-428/Buje.ipt
picts/chain-n-428-cadena-428/Cadena 428.iam
picts/chain-n-428-cadena-428/Concha1.ipt
picts/chain-n-428-cadena-428/Concha2.ipt
picts/chain-n-428-cadena-428/Eslabon interno.iam
picts/chain-n-428-cadena-428/Gancho.iam
picts/chain-n-428-cadena-428/Pasador.ipt
picts/chain-n-428-cadena-428/Piñon 428-14T.ipt
picts/chain-n-428-cadena-428/Rodillo.ipt
picts/flange bearing/ASSEMBLY OF KFL CASING AND BEARING.SLDASM

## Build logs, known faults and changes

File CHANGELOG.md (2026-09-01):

0.0.1
- Repository created
- README
- Config.py

0.0.2
- First frame generated

0.0.3
- Drum added

Version 0.0.5

- FreeCAD development environment working
- GitHub launcher working
- Parametric frame generator working
- Hollow tube generator working
- Ready to add 45° mitres

Version 0.1

- Frame: 45° mitres on both side frames, battery boxes
- Drum: barrel, flanges, shaft, bearings, chain and belt sprockets
- Motor mount and chain drivetrain (QS165, 14T/76T, 5.4286:1)
- Rope intake: self-aligning swivel with rollers, guide wheels, line cutter
- Level wind: Hiwin linear rail, self-reversing screw, flange bearings, jackshaft belt reduction
- Winding pulley and load cell mount on a rod-end pivot
- Electronics architecture decided (not yet built): Fardriver CAN motor controller, ESP32 PID/CAN node, GIGA R1 + Display UI, LoRa pilot handheld - see [`docs/electronics.md`](docs/electronics.md)
- Frame fabrication started in parallel with CAD work - see [`docs/build_log.md`](docs/build_log.md)
- [`docs/rope_calculations.md`](docs/rope_calculations.md): drive-train tension/speed analysis, plus a level-wind synchronization ratio check that found the current jackshaft pulley selection runs the screw ~2x too fast for a flush wind - flagged for a fix before ordering real pulleys

Version 0.2

- Mainboard PCB (ESP32-S3 N16R8 DevKitC-1) fully designed, placed and routed - DRC/ERC clean, ready to order (see [`docs/electronics.md`](docs/electronics.md))
- Fardriver throttle-by-CAN protocol (CAN61) resolved - full VCU control/telemetry frame spec obtained from Fardriver support
- Battery architecture revised: single 30-cell string under one BMS, replacing the earlier two-independent-box-in-series plan
- [`docs/control_philosophy.md`](docs/control_philosophy.md): added a daily calibration step (100 kg reference pull - calibrates the load cell and proof-tests the line)
- Documentation pass: cross-checked and updated against current project state, internal file references made clickable throughout

Unreleased

- Operator-display panel-mount frame ([`gigadisplay_holder/`](gigadisplay_holder/)): parametric FreeCAD bezel that mounts the GIGA Display Shield into the winchman box's front panel. All reference dimensions re-measured from the real board and the second test print fits - LCD window, M3 bolt pattern, screw-head counterbore and RGB-LED light-pipe hole. Panel thickness still a placeholder pending the box choice. See its [README](gigadisplay_holder/README.md).

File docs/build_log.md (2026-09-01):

2026-04-17

✔ Cut 4 × 1500 tubes
✔ Cut 4 × 800 tubes
✔ Tack welded left side frame

2026-09-01

✔ GIGA Display Shield panel-mount frame - second test print fits the real board (dimensions re-measured, see `gigadisplay_holder/`)

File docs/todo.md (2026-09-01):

# TODO

## Frame
- [x] Hollow 50x50x4 tube
- [x] 45° mitres (side frames) - cross members still plain box, not yet hollow/mitred
- [ ] Automatic cut list
- [ ] Weight calculation

## Drum
- [x] 390 mm barrel
- [x] 590 mm flanges
- [x] 50 mm shaft
- [x] Kart sprocket hub (76T chain sprocket + 50T belt sprocket, placeholder envelopes)
- [ ] Inner support discs (config values exist, not yet modelled)

## Drivetrain
- [x] Motor mount + chain drive (motor, 14T/76T sprockets)
- [ ] Motor mount bracket (currently a placeholder envelope, only reference photos exist)
- [ ] **Level-wind belt/jackshaft ratio needs fixing** - current 50T/100T/40T/66T pulley selection gives a 3.3:1 drum:screw ratio, but a 20mm screw lead and 3mm rope needs 6.67:1 for a flush wind (see [rope_calculations.md](rope_calculations.md#level-wind-synchronization-ratio)). Not yet built in real hardware - fix before ordering pulleys.

## Level wind
- [x] Diamond reversing screw (RS2020, real STEP file)
- [x] Hiwin rail (real IGES file)
- [x] Floating guide (rod-end pivot + clevis)
- [x] Load cell pulley

## Electronics
- [x] QS165 motor selected and modelled
- [x] Architecture decided: Fardriver ND961200-CAN controller, ESP32 PID/CAN node, GIGA R1 + Display UI, LoRa handheld (see [electronics.md](electronics.md))
- [x] Resolve Fardriver throttle-by-CAN frame spec - CAN61 protocol obtained from Fardriver support
- [x] Mainboard PCB (ESP32-S3 DevKitC-1) designed, placed, routed, DRC/ERC clean - ordering
- [x] Operator-display panel-mount frame (`gigadisplay_holder/`) - fitted to the real GIGA Display Shield, 3D-printed; box panel thickness still a placeholder
- [x] Define GIGA/handheld JSON protocol and state machine (see [software.md](software.md))
- [ ] Build ESP32 PID/CAN node (firmware) - comms skeleton only so far, no PID/CAN/sensor logic yet
- [ ] Build GIGA R1 + Display UI node - mirror the mainboard's RGB status LED (`state` -> color, see esp32_mainboard.ino's `updateStatusLed()`) on the GIGA's own onboard `LEDR`/`LEDG`/`LEDB` pins; `state` is already in every telemetry message, no protocol change needed
- [ ] Build LoRa pilot handheld + winch-side module - pilot handheld confirmed has a WS2812B RGB LED on GPIO38, same status mirroring trick applies there too
- [ ] PID tension control (tuning, once hardware exists)
- [ ] Pre-flight rope proof test

## Safety
- [ ] 40 kg until tree height
- [ ] Ramp to pilot weight
- [ ] Cable break behaviour

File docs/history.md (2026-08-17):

# Open Paraglider Tow Winch

# History

Version 0.2

---

## The Beginning

Paraglider towing did not start with purpose-built tow winches.

In the early 1980s pilots built their own equipment from whatever was available.

One of the very first systems was remarkably simple.

A car was parked on the beach.

One driven wheel was lifted off the ground and removed.

An empty wheel rim ("velg") was mounted instead.

The tow rope was wrapped around the rim.

A pulley and a spring balance measured the tow force.

The driver watched the spring balance while controlling the engine throttle.

```
Spring Scale
      │
      ▼
     Pulley
      │
      ▼
  Empty Wheel Rim
      │
      ▼
     Car Engine
      │
      ▼
     Pilot
```

Although primitive, the basic principle was already present:

**Control the force applied to the pilot.**

---

## Mechanical Improvements

As towing became more popular, stronger and more reliable winches were built.

Automotive engines with automatic gearboxes became common.

One important discovery was that the torque converter produced a much smoother launch than a direct mechanical connection.

To improve this behaviour even further, additional holes were drilled in the torque converter.

This intentionally increased the slip.

The result was a softer and safer launch.

The purpose was never to reduce performance.

The purpose was to reduce sudden increases in tow force.

---

## Lessons Learned

Many years of practical towing taught an important lesson.

A good tow operator does **not** control rope speed.

A good tow operator continuously controls **tow force**.

The pilot should never notice abrupt changes in pull.

Whether the pilot accelerates, slows down, encounters lift or sink, the tow force should remain predictable.

This philosophy became the foundation of this project.

---

## The Electric Tow Winch

Modern electric motors provide something that mechanical systems never could.

Instead of relying on mechanical slip, the controller can directly regulate the towing force.

The Open Paraglider Tow Winch therefore uses:

- Load cell
- PID controller
- Electric motor
- Motor controller
- Hall sensors
- State machine

The operator changes the set tow force, and the electronics regulates the motor current to hold it.

If the force becomes too low, the drum pulls.

If the force becomes too high, the drum can pay rope out under control.

The behaviour is the same as the experienced tow operators and modified torque converters of earlier generations.

Only the technology has changed.

---

## Design Philosophy

This project is not an attempt to build the fastest tow winch.

It is an attempt to build the safest and most predictable tow winch.

The goal is to reproduce decades of towing experience using modern electronics while keeping the behaviour familiar to experienced operators.

---

## Acknowledgement

This project is dedicated to all the pilots and builders who experimented on beaches, airfields and grass strips during the early years of paragliding.

Without their creativity, practical experience and willingness to experiment, modern tow systems would not exist.

This repository attempts to preserve not only the hardware, but also the engineering philosophy that evolved over more than forty years.

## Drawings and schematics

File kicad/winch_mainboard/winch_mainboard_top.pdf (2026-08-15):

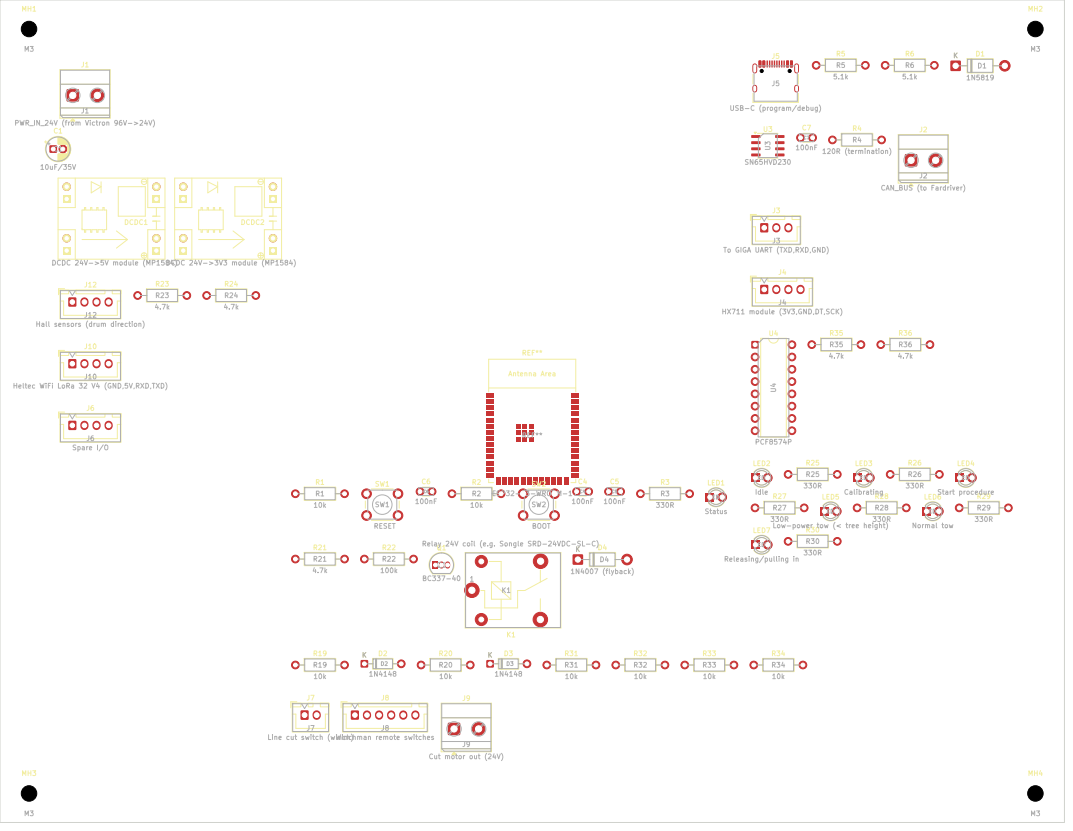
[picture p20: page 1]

To GIGA UART (TXD,RXD,GND) J3 HX711 module (3V3,GND,DT,SCK) J4

Heltec WiFi LoRa 32 V4 (GND,5V,RXD,TXD) J10 Hall sensors (drum direction) J12

Low-power tow (< tree height)

Line cut switch (winch) J7

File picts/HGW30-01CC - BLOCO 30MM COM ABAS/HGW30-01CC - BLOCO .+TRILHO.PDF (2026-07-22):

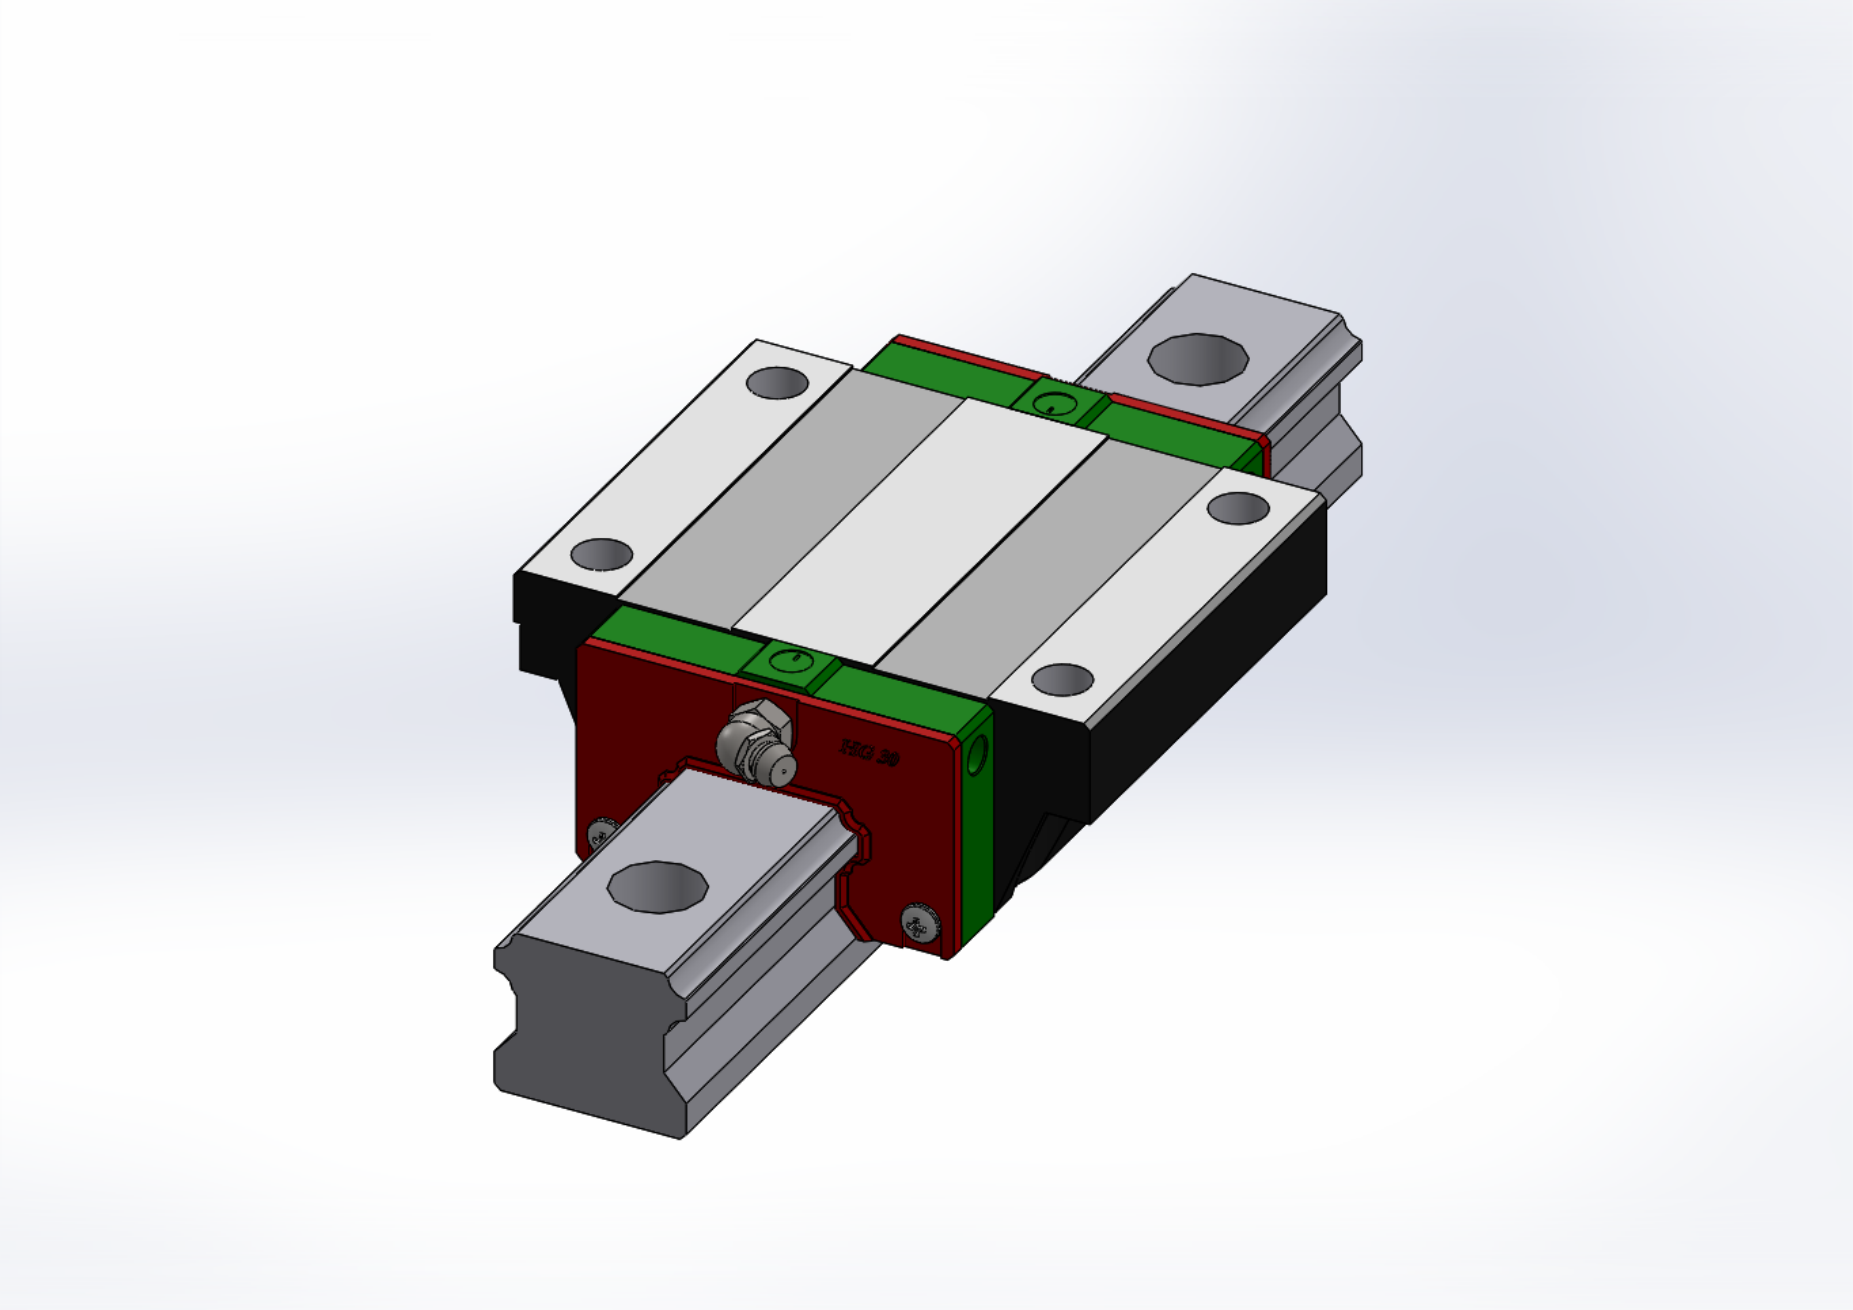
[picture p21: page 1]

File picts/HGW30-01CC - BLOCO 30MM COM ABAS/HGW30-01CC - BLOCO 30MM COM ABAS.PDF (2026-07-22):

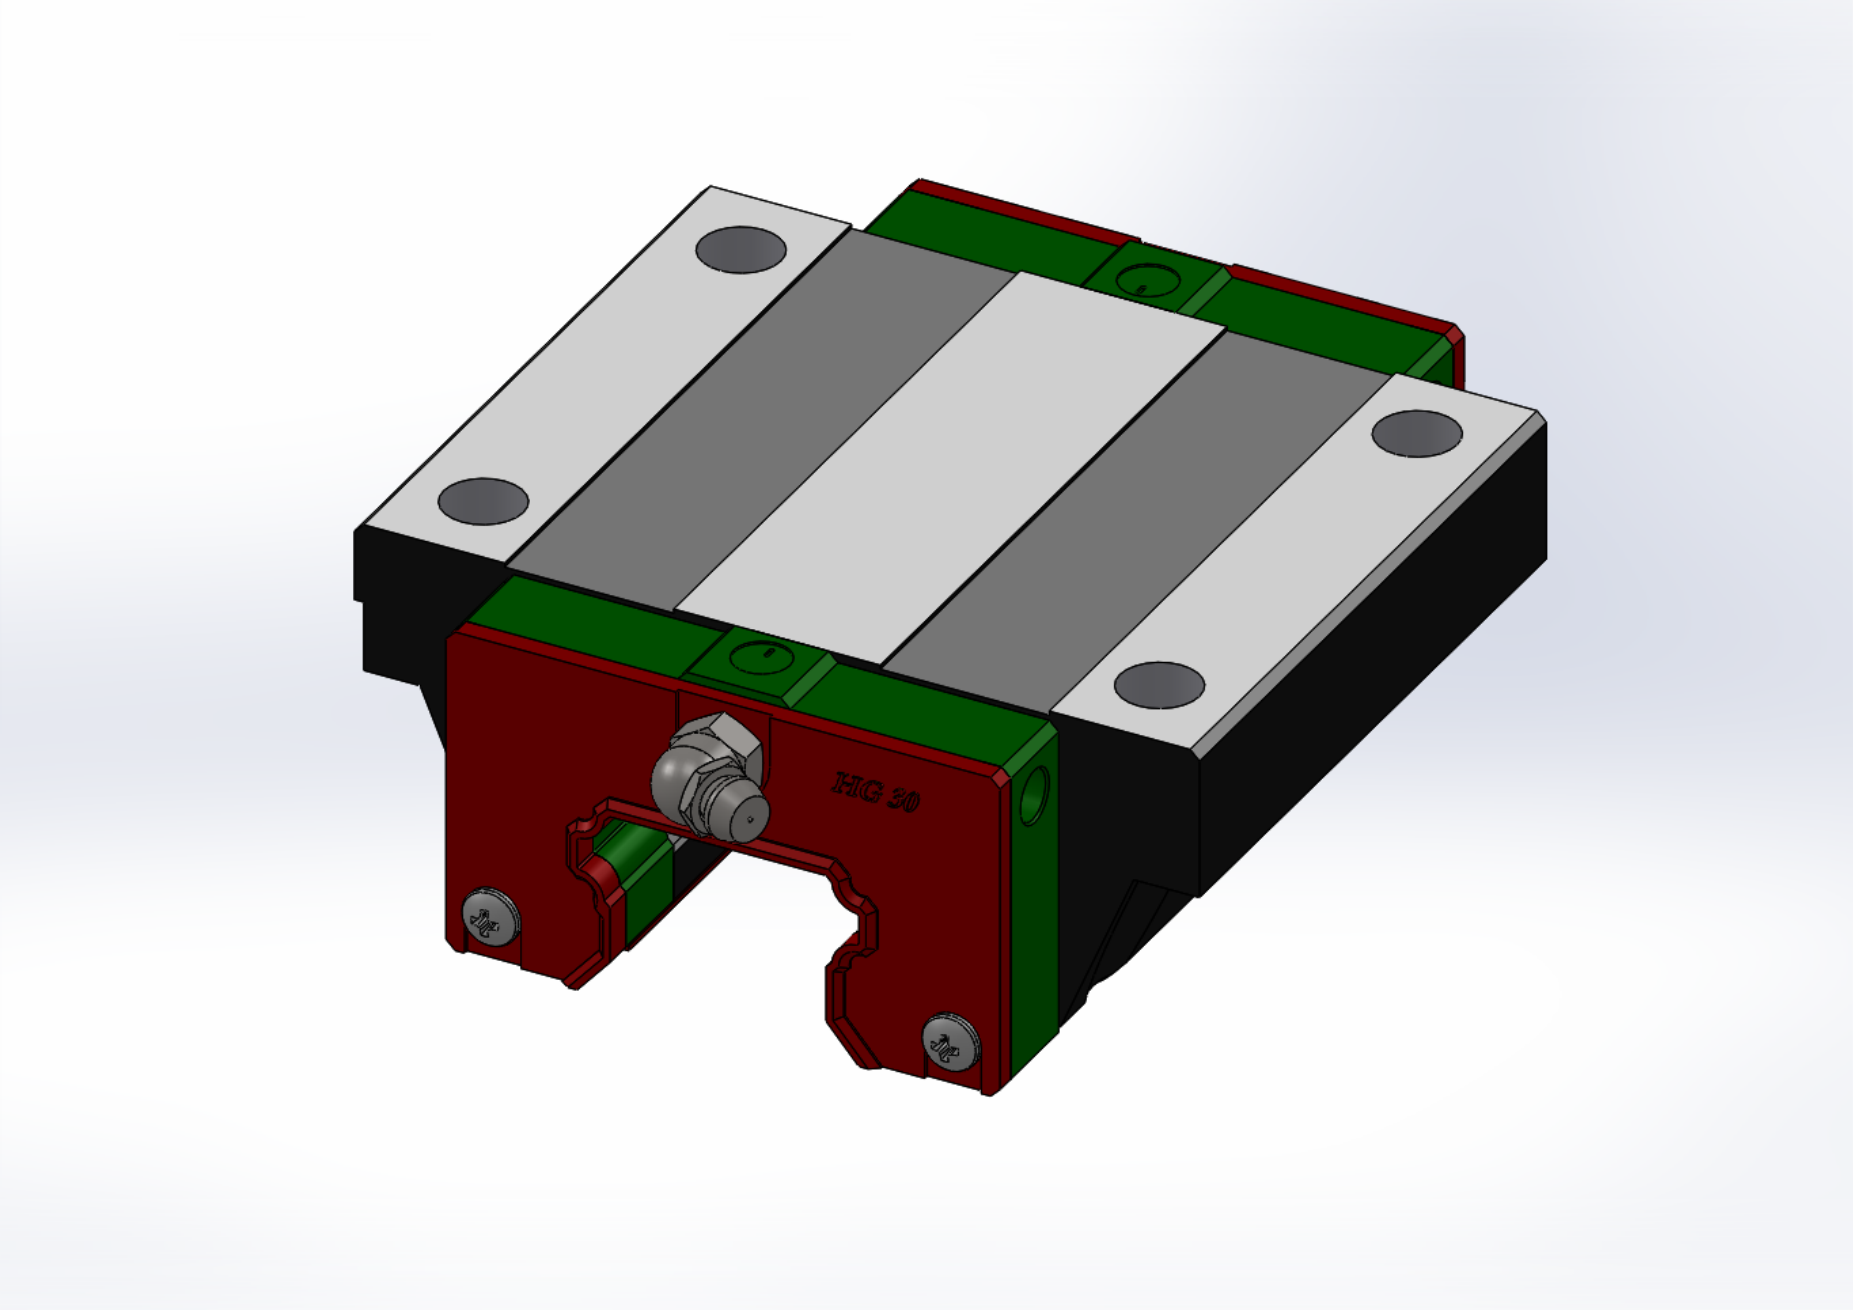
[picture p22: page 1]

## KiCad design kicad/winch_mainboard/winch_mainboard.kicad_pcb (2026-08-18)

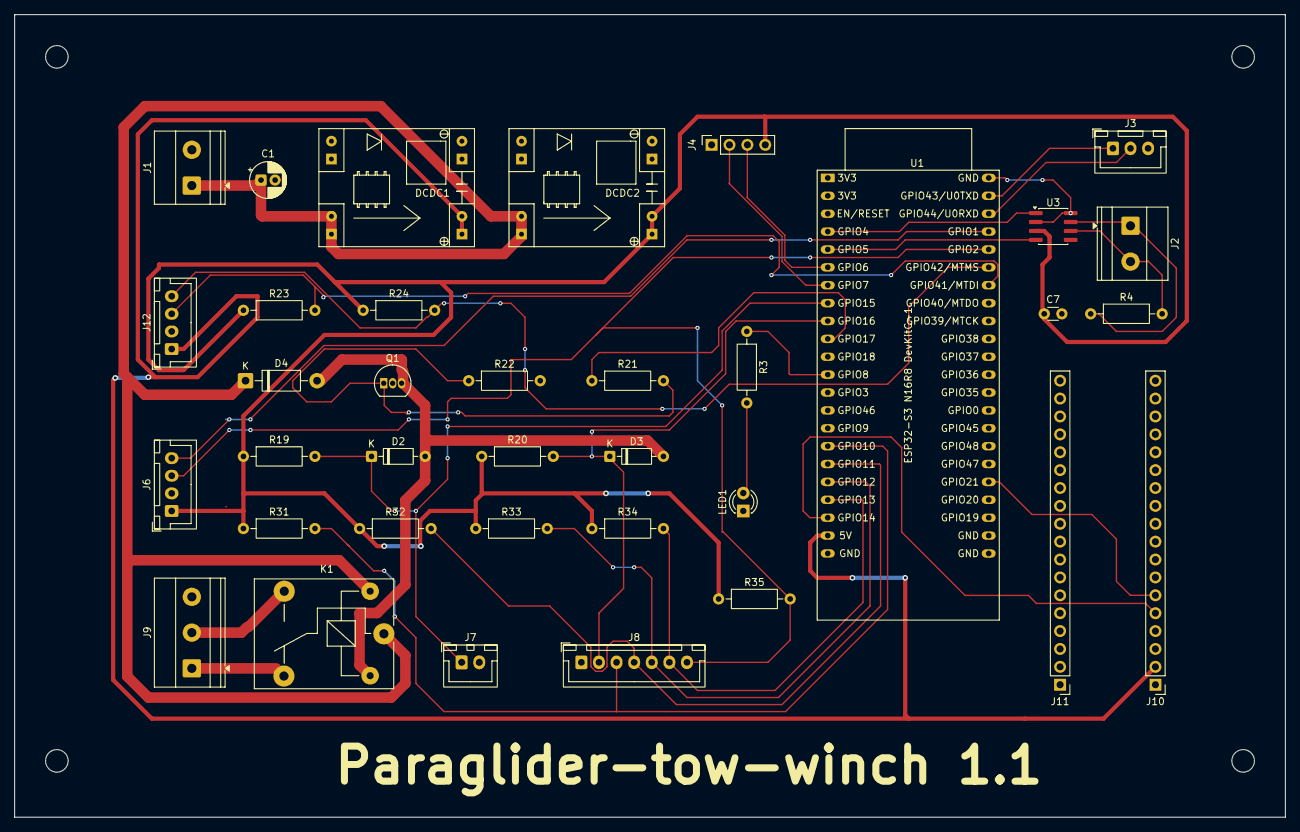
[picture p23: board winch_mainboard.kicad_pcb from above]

Board: 2 copper layers, 180.5 x 114.0 mm, 40 parts (0 on the bottom side), 31 nets.

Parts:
C1: 10uF/35V; CP_Radial_D5.0mm_P2.00mm
C7: 100nF; C_Disc_D3.0mm_W1.6mm_P2.50mm
D2, D3: 1N4148; D_DO-35_SOD27_P7.62mm_Horizontal
D4: 1N4007 (flyback); D_DO-41_SOD81_P10.16mm_Horizontal
DCDC1: DCDC 24V->5V MP1584; MP1584_buck_module
DCDC2: DCDC 24V->3V3 MP1584; MP1584_buck_module
J1: PWR_IN_24V; TerminalBlock_Phoenix_MKDS-1,5-2-5.08_1x02_P5.08mm_Horizont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
J2: CAN_BUS Fardriver; TerminalBlock_Phoenix_MKDS-1,5-2-5.08_1x02_P5.08mm_Horizont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
J3: GIGA UART (TXD,RXD,GND); JST_XH_B3B-XH-A_1x03_P2.50mm_Vertical
J4: HX711 module; PinSocket_1x04_P2.54mm_Vertical
J6: Spare I/O; JST_XH_B4B-XH-A_1x04_P2.50mm_Vertical
J7: Line cut switch; JST_XH_B2B-XH-A_1x02_P2.50mm_Vertical
J8: Winchman remote switches; JST_XH_B7B-XH-A_1x07_P2.50mm_Vertical
J9: Cut motor out (24V); TerminalBlock_Phoenix_MKDS-1,5-3-5.08_1x03_P5.08mm_Horizont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
J10, J11: Heltec; PinHeader_1x18_P2.54mm_Vertical
J12: Hall sensors drum; JST_XH_B4B-XH-A_1x04_P2.50mm_Vertical
K1: Songle SRD-24VDC-SL-C; Relay_SPDT_SANYOU_SRD_Series_Form_C
LED1: Status; LED_D3.0mm
MH1, MH2, MH3, MH4: M3; MountingHole_3.2mm_M3
Q1: BC337-40; TO-92_Inline
R3: 330R; R_Axial_DIN0207_L6.3mm_D2.5mm_P10.16mm_Horizontal
R4: 120R (termination); R_Axial_DIN0207_L6.3mm_D2.5mm_P10.16mm_Horizontal
R19, R20, R31, R32, R33, R34, R35: 10k; R_Axial_DIN0207_L6.3mm_D2.5mm_P10.16mm_Horizontal
R21, R23, R24: 4.7k; R_Axial_DIN0207_L6.3mm_D2.5mm_P10.16mm_Horizontal
R22: 100k; R_Axial_DIN0207_L6.3mm_D2.5mm_P10.16mm_Horizontal
U1: ESP32-S3 N16R8 DevKitC-1; ESP32-S3-DevKitC
U3: SN65HVD230; SOIC-8_3.9x4.9mm_P1.27mm

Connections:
+3V3: C7.1, DCDC2.4, J4.4, J6.1, R19.1, R20.1, R23.1, R24.1, R31.1, R32.1, R33.1, R34.1, R35.1, U3.3
+5V: DCDC1.4, J10.2, J12.1, U1.21
+24V: C1.1, D4.1, DCDC1.1, DCDC2.1, J1.1, K1.1, K1.2
CAN_H: J2.1, R4.1, U3.7
CAN_L: J2.2, R4.2, U3.6
CAN_RX: U1.5, U3.4
CAN_TX: U1.4, U3.1
CUT_MOTOR_A: J9.1, K1.4
CUT_MOTOR_B: J9.2, K1.3
CUT_Q1_BASE: Q1.1, R21.2, R22.1
CUT_RELAY_DRIVE: R21.1, U1.10
CUT_SW1_SENSE: D2.1, J7.1, R19.2, U1.8
CUT_SW2_SENSE: D3.1, J8.2, R20.2, U1.9
ESP32_RXD: J3.2, U1.42
ESP32_TXD: J3.1, U1.43
ESTOP_SENSE: J8.3, R31.2, U1.16
GND: C1.2, C7.2, DCDC1.2, DCDC1.3, DCDC2.2, DCDC2.3, J1.2, J3.3, J4.1, J6.2, J7.2, J8.1, J9.3, J10.1, J12.2, LED1.1, Q1.2, R22.2, U1.22, U1.23, U1.24, U1.44, U3.2, U3.8
HALL_A: J12.3, R23.2, U1.38
HALL_B: J12.4, R24.2, U1.39
HX711_DT: J4.2, U1.7
HX711_SCK: J4.3, U1.6
LED1_A: LED1.2, R3.2
LED_STATUS: R3.1, U1.12
LORA_RXD: J10.6, U1.27
LORA_TXD: J10.5, U1.20
RELAY_COIL_LOW: D2.2, D3.2, D4.2, K1.5, Q1.3
SPARE_GPIO1: J6.4, U1.41
SPARE_GPIO2: J6.3, J8.7, R35.2, U1.40
TENSION_DOWN_SENSE: J8.5, R33.2, U1.18
TENSION_RESET_SENSE: J8.6, R34.2, U1.19
TENSION_UP_SENSE: J8.4, R32.2, U1.17

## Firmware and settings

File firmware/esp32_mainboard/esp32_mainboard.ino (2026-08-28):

// ESP32-S3 (N16R8 DevKitC-1) mainboard firmware - communications skeleton.
//
// Implements the JSON protocol defined in docs/software.md (states, `cmd` and
// `telemetry` messages, field authority, deadman timeout). EMERGENCY_STOPPED
// (local hardware e-stop switch + operator command) and CALIBRATING (two-
// point load-cell calibration sequencing) are real, guarded logic, not just
// placeholder transitions. A physical release switch (GPIO2, the winchman
// remote's 7th pin on J8, own dedicated pull-up R35) lets the winchman end
// a tow without the GIGA link, same as the hardware e-stop. IDLE itself is
// boot-locked: the GIGA must set
// operating_mode, pilot_name and pilot_weight_kg (once per power-up) before
// "calibrate" is accepted; in WINCHMAN_AVAILABLE mode, pilot_name and
// pilot_weight_kg are forgotten again after every release/fault, forcing a
// fresh confirmation for whoever tows next (SOLO_TOW keeps them for the
// session, same pilot throughout) - pilot_name exists for tow-log
// administration (who flew which tow), same reasoning as pilot_weight_kg.
// The GIGA
// can also push a whole tunable config (ramp/reduction %, PID gains, and
// optionally a saved calibration via use_saved_calibration) at boot, read
// from its own SD card - see TowConfig - so these don't need a firmware
// reflash to tune. None of the ramp/PID values are acted on by the control
// loop yet. Handheld lat/lon/baro_alt_m are relayed straight into telemetry,
// log-only, for the GIGA to write out - never used for control here.
// Everything else that depends on real sensors is still stubbed - no
// HX711/hall-sensor reads, no CAN61, no PID, no tree-height/force-ramp
// logic. See docs/software.md's "Current Firmware Status" section for the
// exact list of what's stubbed vs real.
//
// Board setting requirement (Arduino IDE > Tools): "USB CDC On Boot" = Enabled.
// This makes `Serial` the USB-C debug console and `Serial0` the hardware UART0
// on GPIO43/44 (the GIGA link) - get this wrong and the GIGA link silently
// stops working. See docs/software.md's "Transports" table.
//
// Requires the ArduinoJson library (>= 7.0) - install via Library Manager.
//
// The DevKitC-1's onboard RGB LED (GPIO48) shows the current state at a
// glance - see updateStatusLed() - useful on the bench with no display
// hardware wired up yet.
//
// TESTING WITHOUT REAL GIGA/HELTEC HARDWARE: with DEBUG_ACCEPT_SERIAL_COMMANDS
// below, the USB Serial Monitor doubles as a stand-in for both of them - type
// a `cmd` JSON line (e.g. {"type":"cmd","seq":1,"src":"giga","state_cmd":
// "calibrate"}) and hit enter, and it's handled exactly like a real message
// from that link. Telemetry is echoed to the same console so you can watch
// `state` etc. change in response, no extra hardware required. Set to 0 once
// real GIGA/Heltec firmware exists, so the debug console stops doubling as a
// trusted command source.
#define DEBUG_ACCEPT_SERIAL_COMMANDS 1

// OTA firmware updates over WiFi (ArduinoOTA, bundled with the esp32 board
// package - no separate Library Manager install needed, unlike ArduinoJson).
// Bench/development convenience ONLY - see setup()'s connectWifiForOta() for
// why this must never be allowed to block or delay boot: the winch runs at
// a real flying field with no WiFi at all, and the safety-critical control
// firmware must come up exactly the same whether or not a network exists.
// Never trigger an OTA upload while a tow is actually in progress - flashing
// pauses the whole loop (including e-stop polling) for the duration of the
// write, same as any other firmware update; only do this on the bench.
// Set to 0 to strip WiFi/OTA out of the build entirely (e.g. a field build).
#define ENABLE_OTA 1

#include <ArduinoJson.h>
#if ENABLE_OTA
#include <WiFi.h>
#include <ArduinoOTA.h>
#include "secrets.h"  // WIFI_SSID / WIFI_PASSWORD - gitignored, fill in yourself
#endif

// ---------------------------------------------------------------------------
// Pins (see docs/electronics.md's pin map table)
// ---------------------------------------------------------------------------
static const int PIN_HELTEC_TXD = 14;  // ESP32 -> Heltec RXD
static const int PIN_HELTEC_RXD = 21;  // ESP32 <- Heltec TXD
// GIGA link uses hardware UART0 (GPIO43/44) via Serial0 - fixed pins, no remap.
static const int PIN_ESTOP_SENSE = 10;  // active-low, winchman remote e-stop switch
static const int PIN_STATUS_LED = 48;   // onboard addressable RGB LED (DevKitC-1)

// Physical "release" trigger - lets the winchman end a tow cleanly by hand,
// without depending on the GIGA link (see docs/software.md "Field authority":
// state_cmd is otherwise GIGA-only). Wired to J8 (winchman remote, 7-pin)
// pin 7 / SPARE_GPIO2, with its own dedicated 10k pull-up (R35, see
// docs/electronics.md) - same convention as the other four winchman-remote
// switches, not an internal-pull-up-only bodge. GPIO1 (still reachable via
// J6, the spare-I/O connector) remains free for a future addition.
static const int PIN_RELEASE_SENSE = 2;

// Winchman remote tension+5kg/-5kg buttons. Real intended use (per project
// discussion, not yet in docs/electronics.md): live field recalibration -
// while towing, the winchman nudges the load-cell reading by 1kg per press
// to match an external reference scale at the start location, then confirms
// the new 100kg point with the reset-to-programmed/Set button below.
static const int PIN_TENSION_PLUS_SENSE  = 11;
static const int PIN_TENSION_MINUS_SENSE = 12;

// Winchman remote "set to memory"/tension reset-to-programmed button.
// Wired into real logic 2026-08-28: pressed while READY, it starts the tow
// (state_cmd:"start_tow") - the GIGA's own touchscreen Start button was
// removed in favour of this, same reasoning as take-up-slack's -5kg
// trigger (the winchman needs to act the instant the pilot signals ready,
// without navigating a touchscreen). Its originally-documented meaning
// (reset the tension setpoint to programmed, mid-tow) isn't implemented
// yet - these two meanings would apply in disjoint states (READY vs.
// NORMAL_TOW) if/when that one is built, same non-conflicting-reuse
// pattern as the +5kg/-5kg buttons already use.
static const int PIN_TENSION_RESET_SENSE = 13;

// ---------------------------------------------------------------------------
// Timing
// ---------------------------------------------------------------------------
static const uint32_t TELEMETRY_INTERVAL_MS = 200;   // 5 Hz, see docs/software.md
static const uint32_t HANDHELD_TIMEOUT_MS   = 1000;  // deadman link-loss timeout

// ---------------------------------------------------------------------------
// State machine (see docs/control_philosophy.md "State Machine")
// ---------------------------------------------------------------------------
enum class WinchState : uint8_t {
  IDLE,
  TAKING_UP_SLACK,
  CALIBRATING,
  READY,
  LAUNCH,
  UNDER_TREE_HEIGHT,
  NORMAL_TOW,
  PAY_OUT,
  RELEASE,
  RECOVERY,
  EMERGENCY_STOPPED,
};

const char* stateToString(WinchState s) {
  switch (s) {
    case WinchState::IDLE:              return "IDLE";
    case WinchState::TAKING_UP_SLACK:   return "TAKING_UP_SLACK";
    case WinchState::CALIBRATING:       return "CALIBRATING";
    case WinchState::READY:             return "READY";
    case WinchState::LAUNCH:            return "LAUNCH";
    case WinchState::UNDER_TREE_HEIGHT: return "UNDER_TREE_HEIGHT";
    case WinchState::NORMAL_TOW:        return "NORMAL_TOW";
    case WinchState::PAY_OUT:           return "PAY_OUT";
    case WinchState::RELEASE:           return "RELEASE";
    case WinchState::RECOVERY:          return "RECOVERY";
    case WinchState::EMERGENCY_STOPPED: return "EMERGENCY_STOPPED";
    default:                            return "UNKNOWN";
  }
}

WinchState g_state = WinchState::IDLE;

// ---------------------------------------------------------------------------
// Operating mode - reserved for the still-undecided question of whether the
// pilot handheld should be allowed to trigger calibrate/calibration_done
// (currently GIGA-only, see requestStateTransition()/handleCommand()).
//
// With a winchman present, GIGA-only calibrate authority matches the real
// procedure: the start-location person requests calibration by radio, the
// winchman triggers it. Flying solo, there's no winchman to relay to and no
// one at the winch at all, so that restriction would block calibration
// entirely - hence this mode flag, to eventually let the handheld act
// directly in SOLO_TOW.
//
// Not wired into any logic yet - defaults to the current (safe, unchanged)
// behavior. Nothing reads this yet.
enum class OperatingMode : uint8_t {
  WINCHMAN_AVAILABLE,  // current behavior: calibrate is GIGA/winchman-only
  SOLO_TOW,            // reserved: handheld should be able to calibrate directly
};
OperatingMode g_operatingMode = OperatingMode::WINCHMAN_AVAILABLE;

// Set once by the GIGA at boot (operating_mode + pilot_name + pilot_weight_kg,
// see handleCommand()) - all three are required before IDLE will accept
// "calibrate", so a tow can't proceed without the operator having
// deliberately confirmed them for the day. pilot_name/pilot_weight_kg are
// entered live on the winchman controller (GIGA touchscreen) at the winch,
// per tow - never prepared ahead of time from elsewhere, since they change
// with whoever's flying next. None of the three are persisted across a
// reboot; every power-up starts unconfigured, on purpose - stale settings
// from a previous day/pilot must never carry over silently.
struct BootConfig {
  bool operatingModeSet = false;
  bool pilotNameSet = false;
  char pilotName[32] = "";
  bool pilotWeightSet = false;
  float pilotWeightKg = 0;
};
BootConfig g_bootConfig;

// Moved up from its original spot further down (its more natural home,
// next to the handheld-command-handling code) so resetPilotInfoIfWinchman()
// below can clear tensionSetpointKg too, without a forward-reference -
// both this and BootConfig need to exist before that function does.
struct CommandState {
  bool deadman = false;
  bool treeHeight = false;
  float tensionSetpointKg = 0;
  uint32_t lastHandheldCmdMillis = 0;  // 0 = never received
  // Handheld GPS/baro, relayed into telemetry for the GIGA to log - the
  // mainboard doesn't act on these itself, just passes them through (see
  // docs/software.md's GPS/logging design). hasPosition guards against
  // relaying stale 0,0 before the handheld's first fix arrives.
  bool hasPosition = false;
  float lat = 0;
  float lon = 0;
  float baroAltM = 0;
};
CommandState g_cmd;

bool bootConfigured() {
  return g_bootConfig.operatingModeSet && g_bootConfig.pilotNameSet && g_bootConfig.pilotWeightSet;
}

// Winchman-mode-only: after a tow ends (release) or a fault (e-stop), forget
// pilot_name/pilot_weight_kg so the boot-config lock re-engages before the
// *next* tow - forces the winchman to actively (re-)confirm who's flying and
// their weight, rather than silently reusing the previous pilot's info
// (pilot_name matters for tow-log administration with students, same
// reasoning pilot_weight_kg already had for the tow-force calc). Skipped in
// SOLO_TOW: same pilot for the whole session, so both should persist across
// repeat tows instead of forcing re-entry each time.
void resetPilotInfoIfWinchman() {
  if (g_operatingMode != OperatingMode::WINCHMAN_AVAILABLE) return;
  g_bootConfig.pilotNameSet = false;
  g_bootConfig.pilotName[0] = '\0';
  g_bootConfig.pilotWeightSet = false;
  g_bootConfig.pilotWeightKg = 0;
  g_cmd.tensionSetpointKg = 0;  // tow force target tracks pilot weight - clear it with the rest
}

// Tunable control-loop parameters, sent once at boot from the GIGA's SD-card
// config file (see docs/software.md "Boot Configuration") rather than
// hardcoded here - these will need dialing in over real flights/tows, and a
// field-editable file beats a firmware reflash for that. None of these are
// acted on by the control loop yet (PID/ramp logic isn't implemented - see
// docs/software.md "Current Firmware Status") - captured now so the wire
// format and boot flow are ready ahead of that work landing.
struct TowConfig {
  bool loaded = false;
  float underTreeHeightReductionPct = 0;
  float startReductionPct = 0;
  float treeheightToFullTowRampS = 0;
  float startToTreeheightRampS = 0;
  float releaseBeforeTakingInS = 0;
  float pidKp = 0;
  float pidKi = 0;
  float pidKd = 0;
};
TowConfig g_towConfig;

// ---------------------------------------------------------------------------
// Status LED (onboard RGB, GPIO48) - one glance at the board tells you the
// state without a Serial Monitor open. EMERGENCY_STOPPED blinks rather than
// stays solid so it can't be mistaken for a dim/miswired LED at a glance.
// ---------------------------------------------------------------------------
void updateStatusLed(WinchState s) {
  if (s == WinchState::EMERGENCY_STOPPED) {
    bool on = (millis() / 250) % 2;  // ~2 Hz blink
    rgbLedWrite(PIN_STATUS_LED, on ? 255 : 0, 0, 0);
    return;
  }
  switch (s) {
    case WinchState::IDLE:              rgbLedWrite(PIN_STATUS_LED, 20, 20, 20);  break;  // dim white
    case WinchState::TAKING_UP_SLACK:   rgbLedWrite(PIN_STATUS_LED, 0, 100, 255); break;  // sky blue
    case WinchState::CALIBRATING:       rgbLedWrite(PIN_STATUS_LED, 0, 0, 255);   break;  // blue
    case WinchState::READY:             rgbLedWrite(PIN_STATUS_LED, 0, 255, 0);   break;  // green
    case WinchState::LAUNCH:            rgbLedWrite(PIN_STATUS_LED, 255, 0, 255); break;  // magenta
    case WinchState::UNDER_TREE_HEIGHT: rgbLedWrite(PIN_STATUS_LED, 255, 255, 0); break;  // yellow
    case WinchState::NORMAL_TOW:        rgbLedWrite(PIN_STATUS_LED, 0, 255, 100); break;  // teal
    case WinchState::PAY_OUT:           rgbLedWrite(PIN_STATUS_LED, 255, 100, 0); break;  // orange
    case WinchState::RELEASE:           rgbLedWrite(PIN_STATUS_LED, 150, 0, 255); break;  // purple
    case WinchState::RECOVERY:          rgbLedWrite(PIN_STATUS_LED, 0, 200, 255); break;  // cyan
    default:                            rgbLedWrite(PIN_STATUS_LED, 0, 0, 0);     break;
  }
}

// ---------------------------------------------------------------------------
// Shared command state, updated by handleCommand(), read by sendTelemetry()
// and (eventually) the real control loop.
// ---------------------------------------------------------------------------
uint16_t g_telemetrySeq = 0;

// ---------------------------------------------------------------------------
// Load cell calibration (see docs/control_philosophy.md "Calibrating"): a
// two-point calibration against a 100kg reference pull on an external scale.
// The sequencing/data model here is real; the sensor input feeding it is a
// stub until the HX711 is wired up (GPIO6/7) - see readLoadCellRaw() below.
// ---------------------------------------------------------------------------
struct LoadCellCalibration {
  bool valid = false;
  long rawAtZero = 0;
  float countsPerKg = 0;  // (rawAt100kg - rawAtZero) / 100.0
};
LoadCellCalibration g_cal;

// TODO: replace with a real HX711 read (GPIO6/7, see docs/electronics.md).
// Returns 0 for now - every caller of this is real logic, only this one
// function is a stub, so it's a single place to fill in later.
long readLoadCellRaw() {
  return 0;
}
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
void loop() {
#if ENABLE_OTA
  // Cheap/non-blocking when idle - just checks for an incoming OTA request.
  // Only meaningfully does anything if connectWifiForOta() actually got a
  // connection at boot; g_otaReady stays false (and this is a no-op)
  // whenever WiFi wasn't available, e.g. out at the field.
  if (g_otaReady) ArduinoOTA.handle();
#endif

  // Checked first, every loop, and re-asserted unconditionally while held -
  // not just on the rising edge. This is the local hardware e-stop's own
  // authority, independent of both UART links (see docs/electronics.md's
  // line-cut/e-stop reasoning): even if a command somehow changed the state
  // away from EMERGENCY_STOPPED in the same loop iteration, the very next
  // iteration puts it straight back for as long as the switch is down.
  static bool lastEstopPressed = false;
  bool estopPressed = estopSwitchPressed();
  if (estopPressed) {
    if (!lastEstopPressed) {
      Serial.println("Local e-stop switch pressed -> EMERGENCY_STOPPED");
      resetPilotInfoIfWinchman();
    }
    g_state = WinchState::EMERGENCY_STOPPED;
  }
  lastEstopPressed = estopPressed;

  // Physical release trigger - one press requests "release" once (not held
  // continuously like e-stop's override above), same guarded path as the
  // GIGA's own state_cmd:"release" (see requestStateTransition()). Lets the
  // winchman end a tow cleanly by hand even with the GIGA link dead.
  static bool lastReleasePressed = false;
  bool releasePressed = releaseSwitchPressed();
  if (releasePressed && !lastReleasePressed) {
    Serial.println("Local release switch pressed -> requesting RELEASE");
    requestStateTransition("release");
  }
  lastReleasePressed = releasePressed;

  // Tension +5kg/-5kg buttons - simulated 1kg-per-press nudge (see
  // g_simulatedTensionKg's own comment above). A press cancels any
  // in-progress calibration ramp so it doesn't get overwritten next tick.
  static bool lastTensionPlusPressed = false;
  bool tensionPlusPressed = tensionPlusSwitchPressed();
  if (tensionPlusPressed && !lastTensionPlusPressed) {
    g_simRampActive = false;
    g_simulatedTensionKg = min(SIM_TENSION_MAX_KG, g_simulatedTensionKg + 1.0f);
    Serial.printf("Simulated tension +1kg -> %.0f kg\n", g_simulatedTensionKg);
  }
  lastTensionPlusPressed = tensionPlusPressed;

  // Same button, two meanings depending on state (see take_up_slack's own
  // comment above) - IDLE/READY starts take-up-slack, anything else (in
  // practice, CALIBRATING's fine-tune step) does the plain tension nudge.
  static bool lastTensionMinusPressed = false;
  bool tensionMinusPressed = tensionMinusSwitchPressed();
  if (tensionMinusPressed && !lastTensionMinusPressed) {
    if (g_state == WinchState::IDLE || g_state == WinchState::READY) {
      requestStateTransition("take_up_slack");
    } else {
      g_simRampActive = false;
      g_simulatedTensionKg = max(SIM_TENSION_MIN_KG, g_simulatedTensionKg - 1.0f);
      Serial.printf("Simulated tension -1kg -> %.0f kg\n", g_simulatedTensionKg);
    }
  }
  lastTensionMinusPressed = tensionMinusPressed;

  // "Set to memory"/tension reset-to-programmed button - advances the tow
  // one phase per press (see the tow-progression comment above):
  // READY->LAUNCH->UNDER_TREE_HEIGHT->NORMAL_TOW. Each branch's own guard
  // (requestStateTransition()'s READY check, or these two functions' own
  // state checks) makes a press in any other state a safe no-op.
  //
  // 5s debounce lockout, real-hardware bug found 2026-08-28: a single
  // physical press on this button was observed advancing TWO phases at
  // once (e.g. LAUNCH straight to NORMAL_TOW, skipping UNDER_TREE_HEIGHT) -
  // classic mechanical switch bounce, since the plain rising-edge check
  // below has no time component at all and can register two presses
  // milliseconds apart as genuinely separate. Each tow phase takes real
  // time anyway (ramps, waits), so a 5s lockout between accepted presses
  // costs nothing operationally while making bounce harmless.
  static bool     lastTensionResetPressed = false;
  static uint32_t lastTensionResetActionMillis = 0;
  bool tensionResetPressed = tensionResetSwitchPressed();
  if (tensionResetPressed && !lastTensionResetPressed
      && millis() - lastTensionResetActionMillis >= 5000) {
    if (g_state == WinchState::READY) {
      requestStateTransition("start_tow");
      lastTensionResetActionMillis = millis();
    } else if (g_state == WinchState::LAUNCH) {
      advanceToUnderTreeHeight();
      lastTensionResetActionMillis = millis();
    } else if (g_state == WinchState::UNDER_TREE_HEIGHT) {
      advanceToNormalTow();
      lastTensionResetActionMillis = millis();
    }
  }
  lastTensionResetPressed = tensionResetPressed;

  updateSimulatedTensionRamp();
  checkCalibrationRopeInSafety();
  checkTakeUpSlackProgress();
  checkTowLineIn();
  checkReleaseProgress();

  JsonDocument doc;
  if (g_gigaReader.poll(doc)) handleCommand(doc);

  doc.clear();
  if (g_heltecReader.poll(doc)) handleCommand(doc);

#if DEBUG_ACCEPT_SERIAL_COMMANDS
  doc.clear();
  if (g_debugReader.poll(doc)) handleCommand(doc);
#endif

  updateStatusLed(g_state);  // every loop, not just on change - EMERGENCY_STOPPED needs to blink

  static uint32_t lastTelemetryMillis = 0;
  uint32_t now = millis();
  if (now - lastTelemetryMillis >= TELEMETRY_INTERVAL_MS) {
    lastTelemetryMillis = now;
    sendTelemetry();
  }

  // Exercised here just to keep it visible in debug output for now - the
  // real actuation loop will consume effectiveDeadman() once it exists.
  static bool lastDeadman = false;
  bool dm = effectiveDeadman();
  if (dm != lastDeadman) {
    Serial.printf("effective deadman: %s\n", dm ? "true" : "false");
    lastDeadman = dm;
  }
}

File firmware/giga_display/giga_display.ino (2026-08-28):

/*
  GIGA Display Shield - winchman UI

  Splash screen (Arduino teal background, yellow logo) for
  5 seconds, then switches to the homepage. Homepage is a
  placeholder - the real winch UI isn't built yet.

  Same library stack as Arduino's own LVGLDemo example
  (Arduino_H7_Video + Arduino_GigaDisplayTouch + lvgl).

  Before this builds: convert assets/splash_logo.png with the
  LVGL Image Converter (https://lvgl.io/tools/imageconverter),
  LVGL v9 tab:
    - Name: splash_logo
    - Color format: RGB565A8 - NOT plain RGB565 (no alpha
      channel, renders as a solid opaque block) and not
      ARGB8888 (needlessly bigger for this image - only 1 real
      colour is used). RGB565A8 keeps a real per-pixel alpha
      channel for the logo's transparent background/anti-
      aliased edges while staying smaller than full ARGB8888.
    - Output format: C array
  Download the result and drop it next to this .ino file.

  Also needs the "ArduinoJson" library (Library Manager, v7.x)
  for the tow-config API below.

  Tow-config SD card wiring (confirmed against a real GIGA on
  forum.arduino.cc/t/arduino-giga-r1-and-sd-card/1221185 - the
  plain SD library works as-is with this exact wiring, no custom
  SPIClass needed despite MISO/MOSI/SCK being on the GIGA's
  separate SPI1 header rather than the usual SPI pins):
    MISO -> D89, MOSI -> D90, SCK -> D91, CS -> D10, 3.3V, GND
*/

#include "Arduino_H7_Video.h"
#include "Arduino_GigaDisplayTouch.h"
#include "lvgl.h"
#include <WiFi.h>
#include <SD.h>
#include <ArduinoJson.h>
#include <Arduino_GigaDisplay.h> /* GigaDisplayRGB - the Display Shield's own DL1 LED, I2C-driven (see below) */
#include "secrets.h" /* WIFI_SSID / WIFI_PASSWORD - gitignored, fill in yourself */

Arduino_H7_Video         Display(800, 480, GigaDisplayShield);
Arduino_GigaDisplayTouch TouchDetector;

#define ARDUINO_TEAL     lv_color_hex(0x00878F)
#define LIGHT_GREY       lv_color_hex(0xE4E7E7)
#define LIGHT_GREEN      lv_color_hex(0xA9DED6)
#define WIFI_DOT_GREEN   lv_color_hex(0x2ECC71)
#define WIFI_DOT_RED     lv_color_hex(0xE74C3C)
#define SPLASH_DURATION_MS 5000
#define MAX_WIFI_NETWORKS 20
#define WIFI_STATUS_POLL_MS 1000

#define SD_CS_PIN 10
#define TOW_CONFIG_PATH "/tow_config.json"
#define HTTP_PORT 80

static lv_obj_t *splash_screen;
static lv_obj_t *home_screen;
static lv_obj_t *settings_btn;
static lv_obj_t *settings_panel;
static lv_obj_t *content_area;
static lv_obj_t *keyboard;
static lv_obj_t *wifi_status_dot;

/* Boot flow: splash -> mode_select_screen (Solo-tow/Winchman) ->
   pilot_info_screen (Name/Weight) -> home_screen ("Start", idle state). */
static lv_obj_t *mode_select_screen;
static lv_obj_t *pilot_info_screen;
static lv_obj_t *pilot_name_ta;
static lv_obj_t *pilot_weight_value_label;
static lv_obj_t *pilot_info_keyboard;

/* "Start" (home_screen's idle state) layout - separate objects from
   content_area/settings_panel below, which stay a gear-icon-triggered
   overlay for Network/Tow Settings exactly as before. Placeholders only
   for now - real tension display / tow-state controls are the next
   step once designed. */
static lv_obj_t *start_title;
static lv_obj_t *start_grey_panel;
static lv_obj_t *start_green_panel;
static lv_obj_t *start_pilot_label;
static lv_obj_t *start_calibrate_btn;
static lv_obj_t *calibrate_value_label;
static lv_obj_t *calibrate_set_btn;
static lv_obj_t *calibrate_cancel_btn;
static lv_obj_t *tension_gauge_arc;
static lv_obj_t *tension_gauge_label;
static lv_obj_t *tension_gauge_unit_label;
static lv_obj_t *rope_out_value_label;
static lv_obj_t *rope_out_unit_label;

static char  pilot_name[32] = "";
static float pilot_weight_kg = 80.0f;

static char wifi_ssids[MAX_WIFI_NETWORKS][33];
static int  wifi_network_count = 0;
static char selected_ssid[33] = "";

static lv_obj_t   *wifi_password_ta;
static lv_obj_t   *wifi_status_label;
static lv_timer_t *wifi_connect_timer = NULL;

/* Same field names/shape as MQTT_Layout's config/giga_boot_config.json -
   the dashboard is the only place these get edited, this firmware just
   receives the pushed JSON, keeps it in memory and mirrors it to the SD
   card so it survives a power cycle. */
struct TowConfig {
  char  operating_mode[16] = "winchman";
  bool  use_saved_calibration = false;
  int   cal_raw_zero = 0;
  int   cal_raw_100kg = 0;
  int   under_tree_height_reduction_pct = 40;
  int   start_reduction_pct = 60;
  float treeheight_to_full_tow_ramp_s = 6;
  float start_to_treeheight_ramp_s = 6;
  float release_before_taking_in_s = 4;
  float pid_kp = 0;
  float pid_ki = 0;
  float pid_kd = 0;
};

static TowConfig tow_config;
static bool      sd_ready = false;
static WiFiServer http_server(HTTP_PORT);
static bool       http_server_started = false;

// ---------------------------------------------------------------------------
// ESP32 link (GIGA pins D0/D1 -> Arduino object Serial1, NOT Serial0 -
// GIGA's `Serial` is reserved for USB, so the D0/D1 hardware UART the
// datasheet itself labels "Serial 0" is exposed as `Serial1` in code -
// confirmed against Arduino's own docs/forum before wiring this up, not
// guessed). Wired to the ESP32 mainboard's own GIGA-UART pins (GPIO43
// TXD -> here RX, GPIO44 RXD -> here TX), same JSON `cmd`/`telemetry`
// protocol as docs/software.md. First step: just mirror `telemetry`'s
// `state` on the onboard RGB LED, using the exact same colour table as
// esp32_mainboard.ino's updateStatusLed() - proves the link/JSON
// parsing works before building any real UI on top of it.
// ---------------------------------------------------------------------------
struct WinchStateColor {
  const char *state;
  uint8_t     r, g, b;
};

static const WinchStateColor WINCH_STATE_COLORS[] = {
  { "IDLE",              60,  60,  60  },
  { "TAKING_UP_SLACK",   0,   100, 255 },
  { "CALIBRATING",       0,   0,   255 },
  { "READY",             0,   255, 0   },
  { "LAUNCH",            255, 0,   255 },
  { "UNDER_TREE_HEIGHT", 255, 255, 0   },
  { "NORMAL_TOW",        0,   255, 100 },
  { "PAY_OUT",           255, 100, 0   },
  { "RELEASE",           150, 0,   255 },
  { "RECOVERY",          0,   200, 255 },
};
#define WINCH_STATE_COLOR_COUNT (sizeof(WINCH_STATE_COLORS) / sizeof(WINCH_STATE_COLORS[0]))

static char   g_winch_state[24] = "";  // last state seen in a telemetry message, "" = none yet
static float  g_last_tension_kg = 0;   // last tension_kg seen in a telemetry message
static String esp32_line_buffer;

/* Moved up from the Calibrate-flow section below (its more natural home)
   so handle_esp32_telemetry_line() can check it too, without a forward-
   reference - both need it, and this function runs earlier in the file. */
enum class CalibrateStep { NONE, ZERO, HUNDRED };
static CalibrateStep g_calibrate_step = CalibrateStep::NONE;
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

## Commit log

2026-07-20 Add battery box, drum, and bearing modules with real placement
    Battery boxes use actual EEL 48V pack dimensions, flush against the
    rear/outer frame boundary. Drum module (barrel, flanges, shaft) and
    bearing50 (UCF210 placeholder envelope) are placed with verified
    clearances, plus hollow mounting posts for the bearings. Everything
    drum-related is grouped under drum_group and positioned from the new
    DRUM_TO_FRONT_BOUNDARY config variable.
2026-07-20 Add rope/drive train calculations doc
    Stall tension, max rope speed, and tension at 40/50 km/h for the
    14T/76T sprocket pair, plus the sustained-stall thermal margin for
    holding tension in strong high-altitude wind.
2026-08-01 Bring docs up to date: v0.1, electronics architecture, level-wind ratio check
    - readme.md: version 0.1, accurate module status, running instructions, docs index
    - docs/electronics.md (new): Fardriver CAN controller, ESP32 PID/CAN node,
    LoRa handheld, GIGA R1 + Display UI
    - docs/rope_calculations.md: level-wind belt/jackshaft ratio validated against
    the rope-diameter/screw-lead requirement, found ~2x mismatch, flagged before
    real pulleys are ordered
    - docs/todo.md: reconciled checklist with actual build state
    - docs/control_philosophy.md: fixed stale "Kelly" controller reference (Fardriver)
    - CHANGELOG.md: added 0.1 entry
2026-08-01 electronics.md: unified UI protocol, barometric tree-height trigger
    - GIGA (winch operator) and pilot LoRa handheld share one command/telemetry
    protocol over two transports (UART / LoRa)
    - Tree-height trigger: barometric height (auto-zeroed per tow) instead of
    GPS, whose vertical accuracy is too coarse for the ~4m target
    - Flag: raw sensor resolution is not the hard part - vario-grade filtering
    (temp compensation, motion/wind noise rejection) is real work; consider
    reusing an open-source vario filter or reading an existing instrument's
    telemetry output instead of reimplementing sensor fusion from scratch
2026-08-01 electronics.md: add battery pack spec and tows-per-charge estimate
    2x EEL 48V 16kWh boxes in series (96V, 32kWh total), plus a simple
    energy-budget calculation (~78 tows/charge at 70kgf avg force, full
    1500m rope payout, 30% mechanical loss).
2026-08-17 Update electronics.md/todo.md, add PCB renders, remove old testkicad scratch project
    Docs were out of sync with recent decisions: Fardriver CAN61 throttle
    protocol resolved, battery moved to a single 30-cell/single-BMS
    architecture, and the mainboard PCB is now fully placed/routed and
    ready to order. Added top_pcb.png and 3d_pcb.png renders to
    electronics.md. Also drops the old testkicad scratch project and
    untracks .DS_Store/.history noise via a new .gitignore.
    [testkicad.kicad_pcb, testkicad.kicad_sch]
2026-08-17 Docs v0.2: clickable file references, calibration step, wording fixes
    Cross-linked config.py/main.py and other in-repo doc references
    throughout docs/ and the README, added a daily calibration section to
    control_philosophy.md, clarified the tow-force control loop wording in
    history.md, and bumped the documentation version to 0.2 with a
    matching CHANGELOG entry.
2026-08-17 Define GIGA/handheld JSON protocol, add first ESP32 comms firmware
    New docs/software.md defines the cmd/telemetry JSON protocol shared by
    the GIGA UART link and the pilot handheld's LoRa link, including
    per-src field authority and the handheld deadman timeout. Added
    CALIBRATING and EMERGENCY_STOPPED to the state machine in both
    control_philosophy.md and software.md.
    First firmware: firmware/esp32_mainboard/esp32_mainboard.ino implements
    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
2026-08-17 Implement real emergency-stop and calibration logic in ESP32 firmware
    EMERGENCY_STOPPED is now driven by an actual GPIO10 e-stop switch read
    every loop, taking priority over both UART links, and can only be
    cleared by reset_fault once the switch is physically released.
    CALIBRATING implements the real two-point load-cell calibration
    sequence from control_philosophy.md (tare, then a 100kg reference
    point), with only the underlying HX711 read still stubbed. Both
    docs/software.md and the firmware stay in sync on what's real vs
    still-placeholder.
    [esp32_mainboard.ino]
2026-08-17 firmware: drive onboard RGB LED (GPIO48) from winch state
    Gives a visual status readout with no Serial Monitor/display needed on the
    bench - each state gets a distinct color, EMERGENCY_STOPPED blinks red.
2026-08-17 firmware+docs: boot-time operating_mode/pilot_weight_kg lock on IDLE
    GIGA must set both once per power-up before calibrate is accepted -
    settings aren't persisted across reboots, so a stale pilot weight or mode
    from a previous session can never silently carry into a new tow. Also adds
    the OperatingMode enum (winchman/solo) as a reserved hook for the still-
    undecided question of whether solo flying should let the handheld trigger
    calibrate directly.
    [esp32_mainboard.ino]
2026-08-17 todo: note RGB status LED mirroring for GIGA/handheld firmware
    GIGA has its own onboard LEDR/LEDG/LEDB, and telemetry's state field is
    already broadcast to both links, so this is pure firmware work once those
    nodes get built - no protocol change needed. Handheld's touchscreen board
    needs a physical check to confirm it even has an onboard RGB LED.
2026-08-17 todo: pilot handheld also has WS2812B on GPIO38
    All three nodes (mainboard, GIGA, handheld) can now mirror the same status
    LED color scheme once their firmwares are built - no hardware gaps.
2026-08-17 firmware+docs: physical release trigger via J6 spare GPIO2
    Lets the winchman end a tow cleanly by hand even with the GIGA link dead -
    edge-triggered, routes through the same guarded requestStateTransition()
    path as the GIGA's own state_cmd:"release". Winchman remote connector is
    already full at 6/6 pins, so this reuses J6's spare SPARE_GPIO2 (GPIO1
    still free) via a hand-wired jumper rather than a PCB respin. No on-board
    pull-up exists for it yet - relies on the internal INPUT_PULLUP for now.
2026-08-18 firmware+docs: boot-time tow config push, calibration skip switch, per-tow pilot-weight reset, handheld GPS/baro relay
    GIGA now pushes the whole tunable config (ramp/reduction %, PID gains,
    optional saved calibration) at boot from its own SD-card file instead of
    anything being hardcoded in firmware - easier to field-tune over real
    flights. use_saved_calibration (default off) lets the operator explicitly
    skip the mandatory live calibration cycle using a saved reference; off
    leaves the existing daily-proof-pull requirement untouched.
    pilot_weight_kg is now forgotten again after every release/emergency_stop
    in "winchman" mode, re-engaging the boot-config lock before the next tow
    so a new pilot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
    [esp32_mainboard.ino]
2026-08-18 kicad: widen winchman remote (J8) to 7 pins for a proper release-switch pull-up, replacing the planned hand-wired bodge
    J8 was full at 6/6 pins, so the release switch (added last session as a
    firmware-only GPIO2 target) had no clean way to get a real pull-up like
    the other four winchman-remote switches. Instead of the planned hand-wired
    jumper off J6's spare pin, widened J8 to a 7-pin JST-XH connector and
    added R35 (10k, +3V3 to SPARE_GPIO2/GPIO2) - same convention as R31-R34.
    New Conn_01x07 schematic symbol (extended from the stock Conn_01x06
    pattern, same pin pitch). PCB footprint swapped to the stock
    JST_XH_B7B-XH-A_1x07; pins 1-6 keep identical physical positions so
    existing routed copp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
    [winch_mainboard.kicad_pcb, winch_mainboard.kicad_sch]
2026-08-18 kicad: bump board to rev 1.1, R35 routed
    R35's pull-up traces (both pads) and J8 pin 7 routed by hand. DRC clean:
    0 unconnected pads, only pre-existing unrelated warnings remain.
    [winch_mainboard.kicad_pcb, winch_mainboard.kicad_sch]
2026-08-19 firmware+docs: pilot_name boot-config field; document MQTT dashboard Winch page; add logo/screenshot assets
    pilot_name joins operating_mode/pilot_weight_kg as a required boot-config
    field (same per-tow reset in winchman mode, persists in solo) - needed for
    tow-log administration when towing students with a winchman present.
    docs/software.md now also covers the Winch page built into the separate
    MQTT_Layout dashboard: boot-config prep modal, tow-log chart, and the
    GIGA sync HTTP contract that firmware will need to implement.
    [esp32_mainboard.ino]
2026-08-26 Add GIGA display firmware (WiFi, SD, dashboard sync, on-device settings) and gigadisplay_holder mount
    giga_display.ino now covers WiFi (auto-connect + manual), an SD-backed
    tow-config store, the HTTP API MQTT_Layout's dashboard already talks to
    (ping/config GET+PATCH, tows stub), and three touchscreen pages for
    editing Tow Profile/Calibration/PID settings directly on the GIGA.
    docs/software.md updated to match. Also commits the gigadisplay_holder
    FreeCAD mount (built earlier, first physical test print done) and its
    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
    [Giga display shield case top.stl, GigaDisplayHolder-GigaFrame.stl, GigaDisplayHolder.FCStd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]
2026-08-26 GIGA: link ESP32 telemetry to Display Shield's RGB LED
    Reads ESP32 JSON telemetry over UART (Serial1) and drives the
    Display Shield's I2C RGB LED (GigaDisplayRGB) to match winch state,
    confirming the ESP32<->GIGA link end-to-end.
2026-08-27 GIGA/ESP32: calibration flow, tension gauge, OTA updates for the mainboard
    Adds a two-step Calibrate/Start flow on the GIGA (0kg/100kg with a live
    tension gauge and field-recalibration correction), a bench-test tension
    simulation with ramp-up/down and a rope-in safety check on the ESP32, and
    WiFi OTA support (ArduinoOTA) so future ESP32 updates don't need a USB
    cable. Also fixes a pilot-weight display bug and a GIGA crash caused by
    zoomed/scaled label text.
    [esp32_mainboard.ino, giga_display.ino]
2026-08-28 GIGA/ESP32: tow progression, release sequence, and gauge polish
    Full READY->LAUNCH->UNDER_TREE_HEIGHT->NORMAL_TOW->RELEASE flow via
    successive presses of the physical tow-progression button, with a
    guarded release sequence (tension-down ramp, safety re-wait, winch-in
    to a 10m floor). Fixes bench-tested bugs: switch-bounce double-skips
    on the progression button (5s debounce), tension_setpoint_kg never
    being sent so ramps targeted 0 (now tracks pilot_weight_kg), release
    wind-in speed and gauge reading during wind-in. Also centers the
    line-out value+unit on one line, and adds the real bold Montserrat
    font used by the tension gauge.
    [esp32_mainboard.ino, giga_display.ino]
2026-09-01 gigadisplay_holder: re-fit the display frame to the real board
    Every reference dimension re-measured from the physical GIGA Display
    Shield after the first test print fitted poorly:
    - LCD window 88.2x52.75 -> 98x58, re-centred (offset +1.6 / 0) so the
    whole glass module shows through
    - screw-head counterbore 9.7x2.5 -> 6.2x2.8 for a real M3 bolt (5.5mm
    head), was far too wide
    - RGB LED light-pipe hole moved to the measured (-26.5, 37.0)
    - M3 bolt pattern (+-48 / +-35) confirmed unchanged against the real
    96x70 hole spacing
    Second print fits (photo in firmware/giga_display/assets/IMG_2831.jpeg).
    Panel thickness is still a placeholder pending the box choice.
    Adds gigadisplay_holder/REA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
    [GigaDisplayHolder-GigaFrame.stl, GigaDisplayHolder.FCStd, giga_display_frame.stl]

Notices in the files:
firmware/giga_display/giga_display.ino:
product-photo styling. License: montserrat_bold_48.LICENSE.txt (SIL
